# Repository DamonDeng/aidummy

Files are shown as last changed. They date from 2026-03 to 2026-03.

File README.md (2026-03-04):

# Dummy
基于稚晖君原理，木子晓汶PCB二次开发，论坛V2版本模型进行复刻
复刻教学视频链接：
https://www.bilibili.com/video/BV18x421Q7Td/?spm_id_from=333.788&vd_source=a98d716b1df46c01ecbcd3430a76d137

1. 目录描述
- Firmware 包括ref控制板，42，35驱动板所用源代码、ESP32的驱动源码
- Hardware 木子晓汶重新设计的ref控制板，42，35驱动板,的pcb、Gaber、Html所有文件
- Model 目前所有版本复刻dummy机械臂的3D文件
- Software 涵盖 dummy studio 、CTL-Tool、木子开发的simple-cli（待完善）
- Bom 仅为视频链接中V2模型的硬件选型，且对淘宝中出现的链接质量不给予保证
- Docs 包括DH模型参数、谐波减速器参数，PCB外观等

2. 链接
论坛链接 http://dummy.free.mbbs.cc
虚拟机链接：https://pan.baidu.com/s/1SL0wGHDJy_RRZEXTTFYR3g 提取码：1234
网页端串口调试助手 serial.keysking.com
烧录工具下载 https://vcon.io/docs/#quickstart 
Fusion360 https://www.autodesk.com.cn/products/fusion-360/trial-intake
VSCODE 下载地址https://code.visualstudio.com/

3.声明
本视频中讲解的教学内容仅用于，Dummy复刻爱好者学习使用，禁止一切商用行为。

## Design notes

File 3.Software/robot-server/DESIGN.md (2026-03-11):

# Robot Server — Design Documentation

**Project:** Dummy X Robot Arm API Server  
**Location:** `3.Software/robot-server/`  
**Last updated:** 2026-03-11

---

## Overview

The robot server is a FastAPI HTTP/WebSocket server that bridges hardware (robot arm + depth camera) into a clean REST API. It runs locally on the host MacBook at `http://127.0.0.1:3001` and is intended to be called by AI agents, scripts, or any HTTP client.

```
AI Agent / Script
      │
      │  HTTP REST  (port 3001)
      ▼
 robot_server.py   (FastAPI)
      │
      ├── /robot/*     ──► Fibre USB ──► Robot Arm (STM32)
      │
      ├── /camera/*    ──► camera_manager.py
      │                         ├── RGBCamera   ──► imagesnap ──► Astra Pro HD Camera (UVC)
      │                         └── DepthCamera ──► depth_capture (C++) ──► Astra Pro Depth (OpenNI)
      │
      ├── /sequences/* ──► sequences.json (persistent named motion library)
      │
      └── /server/*    ──► mode switch (high_level / low_level)
```

---

## Module Breakdown

### `robot_server.py` — Main FastAPI application

The central server. Handles all HTTP routing and delegates to hardware layers.

**Design principles:**
- All blocking operations run in `asyncio.run_in_executor` to avoid blocking the event loop
- Sim mode (`--sim` flag) replaces hardware with a software mock — same API, same interface
- Stop flag pattern: `POST /robot/stop` sets a flag; all motion commands check it first
- Endpoints are grouped by tag: `Robot`, `Sequences`, `Camera`, `Server`

**Startup sequence:**
1. Parse `--sim` flag
2. If real hardware: connect via Fibre USB, configure joint parameters
3. Start FastAPI app on `127.0.0.1:3001`

---

### `camera_manager.py` — Camera abstraction layer

Provides a clean Python interface to both cameras. Uses subprocess bridging (Phase 1).

**Design decision: subprocess vs ctypes**

We chose subprocess bridging for Phase 1 because:
- The C++ binary (`depth_capture`) was already proven working during experimentation
- Zero risk of crashing the Python server (isolated process)
- Easy to debug (binary can be tested independently)
- Acceptable latency for current use case (~3–4s per capture)

Phase 2 (future): ctypes persistent driver — load `libOrbbecSDK.dylib` directly into Python, keep device open, enable streaming at 7–30fps.

**`RGBCamera`**
- Uses `imagesnap` subprocess (macOS CLI tool)
- Device: `"Astra Pro HD Camera"` (UVC — recognized as standard webcam)
- 2-second warmup for auto-exposure stabilization

**`DepthCamera`**
- Runs `depth_capture` binary via subprocess
- Sets `DYLD_LIBRARY_PATH=orbbec_sdk/` so the binary finds its dylibs
- Parses the **last non-empty stdout line** as JSON — SDK logs appear on earlier lines
- Singleton pattern: `CameraManager.get()`

---

### `depth_capture.cpp` — C++ depth capture tool

Standalone binary that captures one depth frame and saves a colorized PNG.

**Why C++ instead of Python?**
- OrbbecSDK only ships pre-built dylibs for C/C++ API on macOS
- `pyorbbecsdk` has no macOS builds (Linux/Windows only)
- The C++ approach proved working in experimentation; wrapping it is lower risk than reimplementing in Python

**Key implementation details:**
- Requests `OB_FORMAT_Y11` (NOT `OB_FORMAT_Y16`) — the SDK auto-unpacks Y11/Y12 to 16-bit mm values; requesting Y16 causes "No matched profile found" error
- Warms up 11 frames before capturing (first frames are often noisy or under-exposed)
- SDK logs print to stdout during `ob::Context` construction before any log-level call can suppress them — Python wrapper reads only the last stdout line
- Colormap: HSV H=0°(red) → H=240°(blue), auto-scaled to p5–p95 percentile range (avoids outlier clipping)

**Build:**
```bash
make depth_capture
# Requires: clang++, orbbec_sdk/include/, orbbec_sdk/libOrbbecSDK.dylib
```

---

### `orbbec_sdk/` — Orbbec SDK dylibs + headers

Pre-built macOS arm64/x86 universal binaries from OrbbecSDK v1.10.16.

**Why Astra Pro works despite not being "officially supported" on macOS:**
The macOS dylib contains an `OpenNIDeviceInfo.cpp` code path that handles legacy OpenNI protocol devices. The Astra Pro (PID 0x0403) speaks OpenNI protocol and is matched by this path. The official supported device list only covers newer UVC-based devices, but the OpenNI path was compiled in.

**Contents:**
- `libOrbbecSDK.dylib` — main SDK library
- `libob_usb.dylib` — custom USB communication (libusb-based)
- `liblive555.dylib` — network streaming (dependency)
- `include/` — C++ headers for `ob::Context`, `ob::Pipeline`, etc.

---

### `ik_solver.py` — Python IK solver

Analytical closed-form IK solver, ported from the STM32 firmware `DOF6Kinematic::SolveIK`.

**Why Python?**
- Enables pre-computing full paths before streaming to hardware
- 20,000 solves/sec — fast enough for real-time streaming
- Exact match to firmware: same Euler convention (Rz·Ry·Rx), same joint config selection

---

### `sequences.json` — Named motion library

Persistent JSON file storing named sequences (e.g., `elbow-wave`, `home-to-rest`).

**Structure:**
```json
{
  "sequence-name": {
    "name": "sequence-name",
    "description": "...",
    "speed": 20,
    "steps": [
      {"joints": [j1, j2, j3, j4, j5, j6], "duration_ms": 1000},
      ...
    ]
  }
}
```

---

## Camera API Design

### Endpoint design rationale

| Endpoint | Rationale |
|---|---|
| `GET /camera/rgb` | Simplest — just a JPEG image, usable by any client |
| `GET /camera/depth` | Standard 640×480, balance of speed and detail |
| `GET /camera/depth/hires` | 1280×1024 for when precision matters (object detection) |
| `GET /camera/depth/stats` | Stats-only when image not needed (faster, less bandwidth) |
| `GET /camera/snapshot` | Parallel RGB+depth capture for synchronized frames |

**All endpoints are async** — blocking work runs in thread pool via `run_in_executor`.

**Image format choices:**
- RGB → JPEG (smaller, lossy acceptable for visual reference)
- Depth → PNG (lossless required — depth values must be exact)

### Depth colormap

Red→Yellow→Green→Cyan→Blue (HSV 0°→240°):
- **Red** = closest objects (near camera)
- **Blue** = furthest objects (far from camera)
- **Dark gray** = no data (IR dropout on dark/shiny surfaces, or out of range)
- **Auto-scaled** to p5–p95 of valid pixel range — avoids single bright/dark pixel washing out the color range

### Known limitations
1. **~3–4s latency per depth capture** — subprocess startup + 11-frame warmup. Acceptable for single captures; not for streaming.
2. **USB cooldown needed** — rapid successive depth captures can time out; the device needs ~5s between calls.
3. **Dark surface dropout** — robot arm body mostly missing from depth map (black anodized aluminum + black housing). Normal behavior for structured-light cameras.
4. **No depth-to-color alignment** — depth and RGB frames are not spatially aligned (D2C). The depth module and RGB lens are ~5cm apart on the device. Alignment requires OrbbecSDK D2C pipeline (future work).

---

## Robot Arm API Design

### Joint space vs Cartesian space

The arm exposes both:
- **`/robot/move_j`** — direct joint angles (degrees). Fast, predictable, no IK required.
- **`/robot/move_l`** — Cartesian target (x, y, z in mm + a, b, c Euler angles). IK solved server-side in Python (`ik_solver.py`).
- **`/robot/move_l_path`** — pre-computes IK for a full path in Python, streams MoveJ at configurable interval. Enables smooth Cartesian motion.

### Stop flag pattern

`POST /robot/stop` sets a server-side flag. All motion endpoints check this flag and reject commands if set. The flag is cleared by: `/robot/homing`, `/robot/resting`, `/robot/z_home`, `/robot/play_sequence`.

This prevents motion commands from firing after an emergency stop without explicitly resetting to a known safe state.

### Named sequences

Sequences are stored in `sequences.json` and managed via CRUD endpoints. A sequence is a list of joint-angle waypoints with timing. Playing a sequence moves through each waypoint at the configured speed.

---

## Future Roadmap

### Phase 2 Camera: ctypes persistent driver
Replace subprocess with direct `libOrbbecSDK.dylib` loading via Python ctypes:
- Device stays open between API calls → eliminates 3–4s startup latency
- Enables streaming via WebSocket at up to 7fps (1280×1024) or 30fps (640×480)
- New endpoint: `WS /camera/stream`

### Object Detection
`POST /camera/objects/detect`:
1. Capture 1280×1024 depth frame
2. Estimate desk plane (RANSAC or mean of flat region)
3. Find pixels elevated above plane by threshold (e.g. >10mm)
4. Connected component labeling → individual objects
5. Per-object: compute centroid (u, v) → project to 3D (X, Y, Z) using camera intrinsics
6. Return: `[{"id": 0, "x_mm": 245, "y_mm": 180, "z_mm": 142, "w_mm": 45, "h_mm": 30}]`

### Pick-and-Place Loop
```
GET /camera/objects/detect
    → object (X, Y, Z) in camera frame
    → transform to robot arm base frame (requires calibration)
    → POST /robot/move_l  (approach position above object)
    → activate gripper
    → POST /robot/move_l  (lift)
    → POST /robot/move_l  (place position)
    → release gripper
```

### Camera-to-Robot Calibration
Hand-eye calibration: move arm to known positions, observe tip in camera frame, solve for rigid transform between camera frame and robot base frame.

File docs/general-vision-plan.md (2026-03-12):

# General Vision System Plan
*Written: 2026-03-12*

## Goal

Build a general-purpose, environment-agnostic pick-and-place system that:
- Works anywhere (no desk-specific calibration, no environment-specific setup)
- Uses Large Vision Models for object understanding (natural language queries)
- Self-calibrates using the arm itself as the reference target
- Looks like a polished product, not a lab prototype

---

## Architecture Overview

```
User command: "pick up the yellow cup"
        │
        ▼
[Scene Understanding Module]
  RGB frame → VLM (Claude / GPT-4o / Gemini)
  "locate the yellow cup" → pixel bounding box (x, y)
        │
        ▼
[3D Grounding Module]
  pixel (x, y) → depth lookup → 3D point in camera frame
  + camera intrinsics
        │
        ▼
[Coordinate Transform]
  camera frame → robot base frame
  (via stored hand-eye calibration matrix)
        │
        ▼
[Motion Planning]
  3D target position → IK solver → joint angles
  + pre-grasp approach + grasp + lift
        │
        ▼
Robot executes
```

---

## Module 1: Self-Calibration (`arm_calibration.py`)

### Concept
Use the arm tip itself as the calibration target — no markers, no special hardware.
The arm's FK always gives exact 3D tip position. Move to N known positions, detect
the tip in the image via VLM, then solve for camera pose with PnP.

### Process
1. Move arm tip to 8 positions spanning the workspace (FK gives us ground-truth 3D XYZ)
2. At each position: capture RGB photo
3. Ask VLM: *"What are the pixel coordinates (x, y) of the robot arm's tip in this image?"*
4. Collect 8× (3D_point, 2D_pixel) pairs
5. Run cv2.solvePnP() → camera rotation + translation relative to arm base
6. Store as `calibration/camera_to_robot.json`

### Trigger
- API endpoint: `POST /robot/calibrate`
- Re-run only when camera is physically moved

### Key design decisions
- Arm tip can have a **distinctive colored cap** (coral, gold, etc.) — elegant, not a marker
- 8 positions chosen to span the full workspace volume (varying J1, J2, J3)
- VLM provides robustness: works even if arm partially overlaps background
- Fallback: manual pixel annotation if VLM confidence is low

---

## Module 2: Scene Understanding (`scene_understanding.py`)

### Concept
VLM (Claude Vision / GPT-4o) handles all object recognition.
No trained models, no color thresholds, no environment-specific logic.
Generalizes to any object describable in natural language.

### API
```
GET /objects/find?query=yellow+cup
→ {"object": "yellow cup", "pixel_x": 342, "pixel_y": 218, "confidence": 0.92,
   "x_mm": 145.2, "y_mm": -82.3, "z_mm": 48.7}
```

### Process
1. Capture RGB + depth frame
2. Send RGB to VLM: *"Find the {query}. Return its center pixel as JSON: {x, y}"*
3. Look up depth at (x, y) → distance from camera
4. Apply camera intrinsics: pixel → ray → 3D point in camera frame
5. Apply hand-eye transform → 3D in robot frame
6. Return full result

### VLM prompt design
- Structured output request (JSON mode)
- Include image + concise instruction
- Confidence scoring via follow-up: "How confident are you? 0-1"
- Fallback: ask for bounding box if point is uncertain, use center

---

## Module 3: Coordinate Transform

### Camera Intrinsics (Astra Pro)
- Depth camera: known from OrbbecSDK calibration data
- RGB camera: can be estimated via OpenCV calibration checkerboard (one-time)
- Or: use Astra Pro factory intrinsics (640×480: fx≈570, fy≈570, cx=320, cy=240)

### Hand-Eye Transform
- 4×4 homogeneous matrix: `T_robot_camera`
- Solved by `arm_calibration.py` via PnP
- Stored in `calibration/camera_to_robot.json`
- Format: rotation (3×3) + translation (3×1), in mm

### Pixel → 3D
```python
d = depth_frame[y, x]  # mm
X = (x - cx) * d / fx
Y = (y - cy) * d / fy
Z = d
point_camera = [X, Y, Z, 1]
point_robot = T_robot_camera @ point_camera
```

---

## Module 4: Motion Planning (Existing + Extensions)

### Existing
- IK solver (`ik_solver.py`) — fast, analytical, 0.05ms per solve ✓
- `/robot/move_j`, `/robot/move_l_path` — working ✓

### New: Grasp Planning
- Pre-grasp approach: come from above at +100mm Z offset, then descend
- Orientation: J4/J5 to align gripper with object's longest axis (from VLM shape description)
- Contact detection: monitor joint torques or use depth delta

---

## Hardware Design Notes (for Damon to work on)

### Philosophy: Look Designed, Not Experimental

Every modification should look like it was always intended — not added for testing.

### Ideas
1. **Arm tip cap** — small colored sphere/dome, 3D-printable
   - Snap-on design over existing tool tip
   - Distinctive color (coral #FF6B6B, or metallic gold, or electric blue)
   - ~20–25mm diameter — large enough to detect, small enough to look natural
   - This doubles as a calibration reference + visual anchor for VLM

2. **Custom color scheme**
   - All industrial robots have a signature color — KUKA orange, ABB mustard, Fanuc yellow
   - Suggestion: matte black body + accent color at joints (orange rings, or white bands)
   - Or: two-tone matte white + color accents (cleaner, camera-friendly)

3. **Link surface treatment**
   - Forearm link (J3→J5): matte finish helps depth camera (less IR specular)
   - Base + shoulder: could be different color = natural "design accent" + helps VLM distinguish arm segments
   - Avoid pure black on surfaces that face the depth camera (IR dropout)

4. **Logo / identity**
   - A custom nameplate or laser-etched logo on the base
   - Makes it look like a product, not a prototype

---

## Implementation Roadmap

### Phase 1: Prove VLM Tip Detection (Current)
- [x] Concept validated (this document)
- [ ] Move arm to 2 positions, capture photos
- [ ] Test VLM tip pixel detection accuracy
- [ ] Validate: returned (x, y) matches visible tip location

### Phase 2: Full Self-Calibration
- [ ] Build `arm_calibration.py` with 8-pose routine
- [ ] Integrate cv2.solvePnP
- [ ] `POST /robot/calibrate` endpoint
- [ ] Store + load calibration matrix

### Phase 3: Scene Understanding
- [ ] Build `scene_understanding.py`
- [ ] `GET /objects/find?query=...` endpoint
- [ ] Test with various objects and environments

### Phase 4: End-to-End Pick-and-Place
- [ ] Connect all modules
- [ ] Test in original desk setup
- [ ] Test in a new environment (prove generalization)

---

## Files

| File | Location | Status |
|---|---|---|
| This plan | `docs/general-vision-plan.md` | ✓ |
| IK solver | `3.Software/robot-server/ik_solver.py` | ✓ existing |
| Robot server | `3.Software/robot-server/robot_server.py` | ✓ existing |
| Calibration module | `3.Software/robot-server/arm_calibration.py` | planned |
| Scene understanding | `3.Software/robot-server/scene_understanding.py` | planned |
| Calibration data | `3.Software/robot-server/calibration/camera_to_robot.json` | planned |

---

*This system makes the arm general-purpose. The arm + camera become a reusable platform
that can be placed anywhere and told what to do in plain language.*

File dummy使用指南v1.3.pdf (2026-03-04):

Made by zRed

Dummy 组装细节与使用指南

论坛链接 http://dummy.free.mbbs.cc

(木子晓汶版开源链接)https://gitee.com/switchpi/dummy/tree/auk (auk 分支) 虚拟环境下载网盘地址
链接：https://pan.baidu.com/s/1SL0wGHDJy_RRZEXTTFYR3g 提取码：1234 网页端串口调试助手 serial.keysking.com 烧录工具下载 https://vcon.io/docs/#quickstart （我也会上传到论坛）

1 电路连接

Ref to j1 使用同向线，需要交换中间两根 canbus 线 剩下 j1 至 j6 的连接都使用反向线

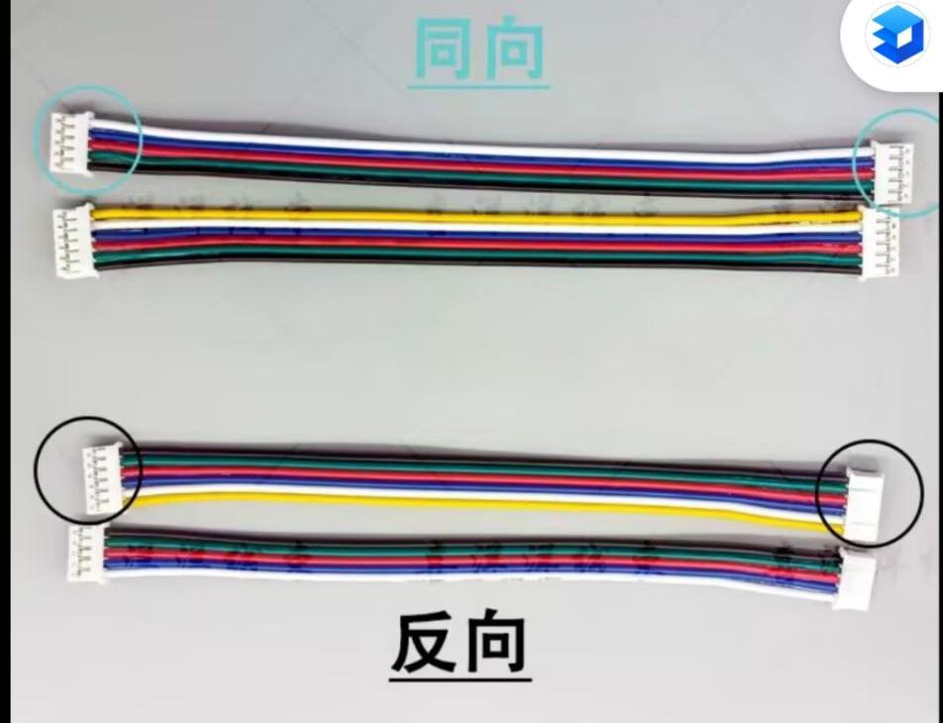
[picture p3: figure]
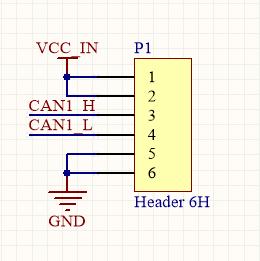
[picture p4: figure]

从原理图可以看出，电源线是两根一组（电机驱动和
ref 板都是这样）

6pin 接口左边 IN 侧 24v 丝印处为 24V,右边 out 侧实际 24v 在左边（靠 IN 侧）
下面有更详细定义

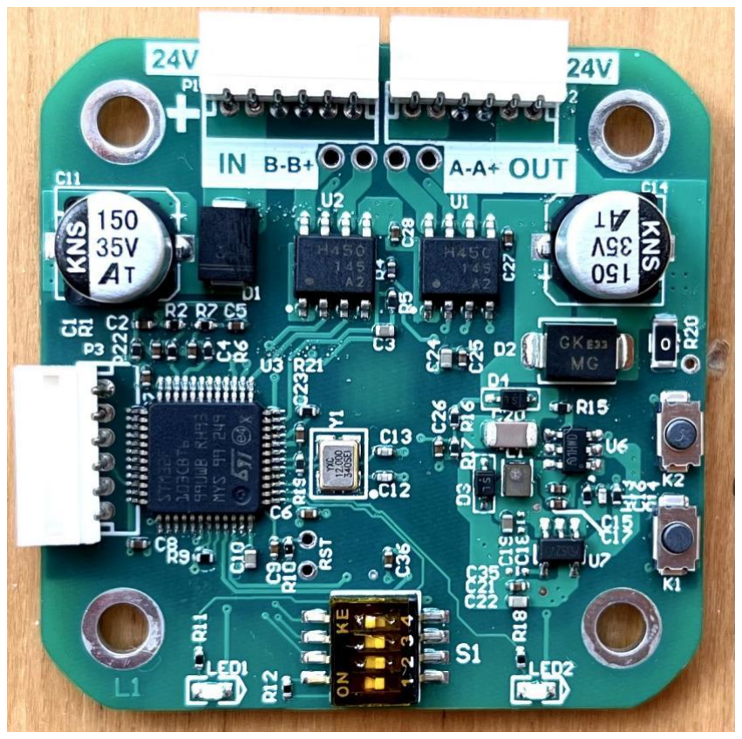
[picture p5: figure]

注意上面两个 6pin 接口的 IN 和 OUT,上一级的 OUT 接上反向线后连到下一级 的 IN 左下第三个 6pin 接口则是程序烧录接口，别接错了

手绘的接线图（偷个懒）
正极线上的那个圆的是自锁开关

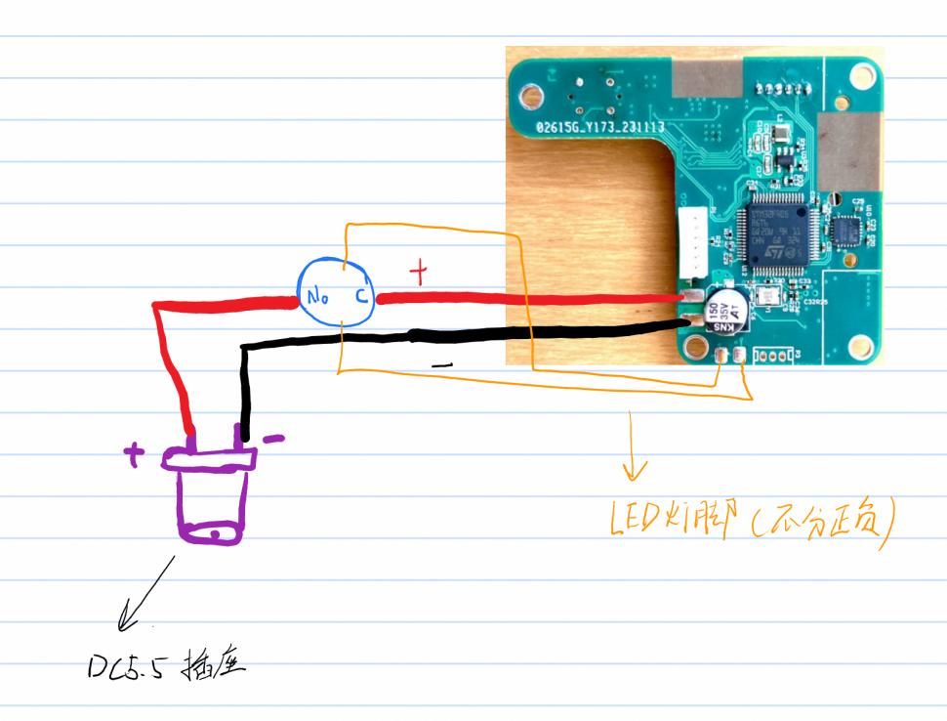
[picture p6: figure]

下面是一些引脚定义，以及拨码方式 注意 j1 到 j6 拨码开关从 1 开始

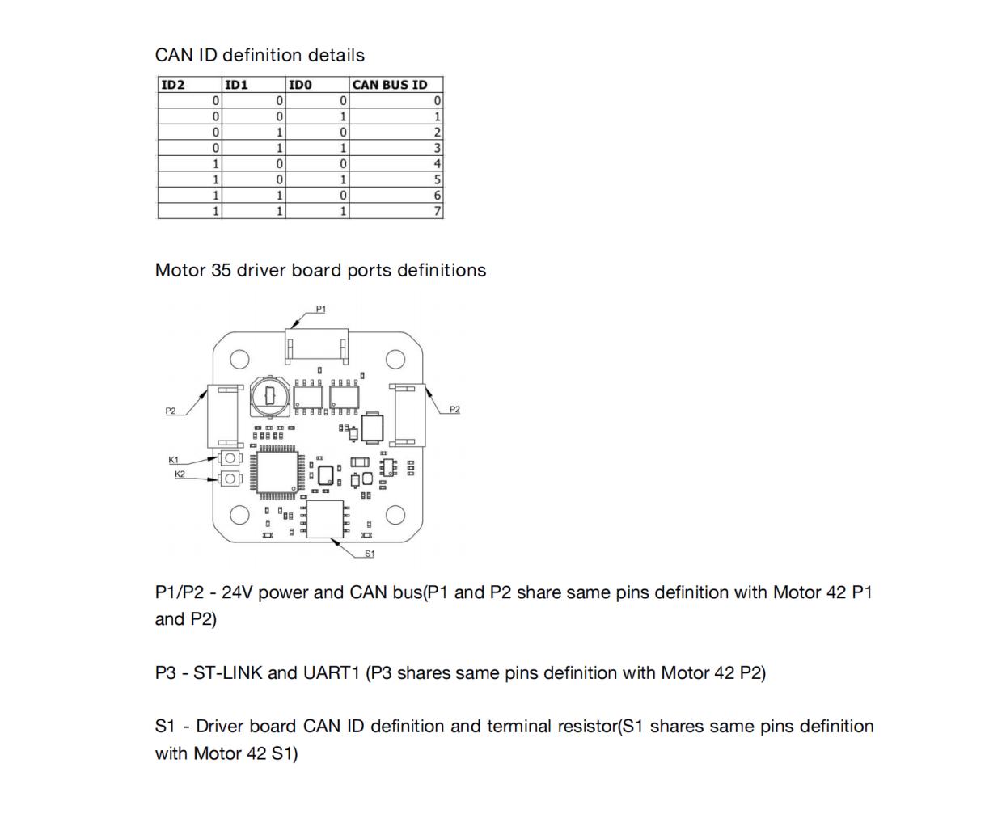
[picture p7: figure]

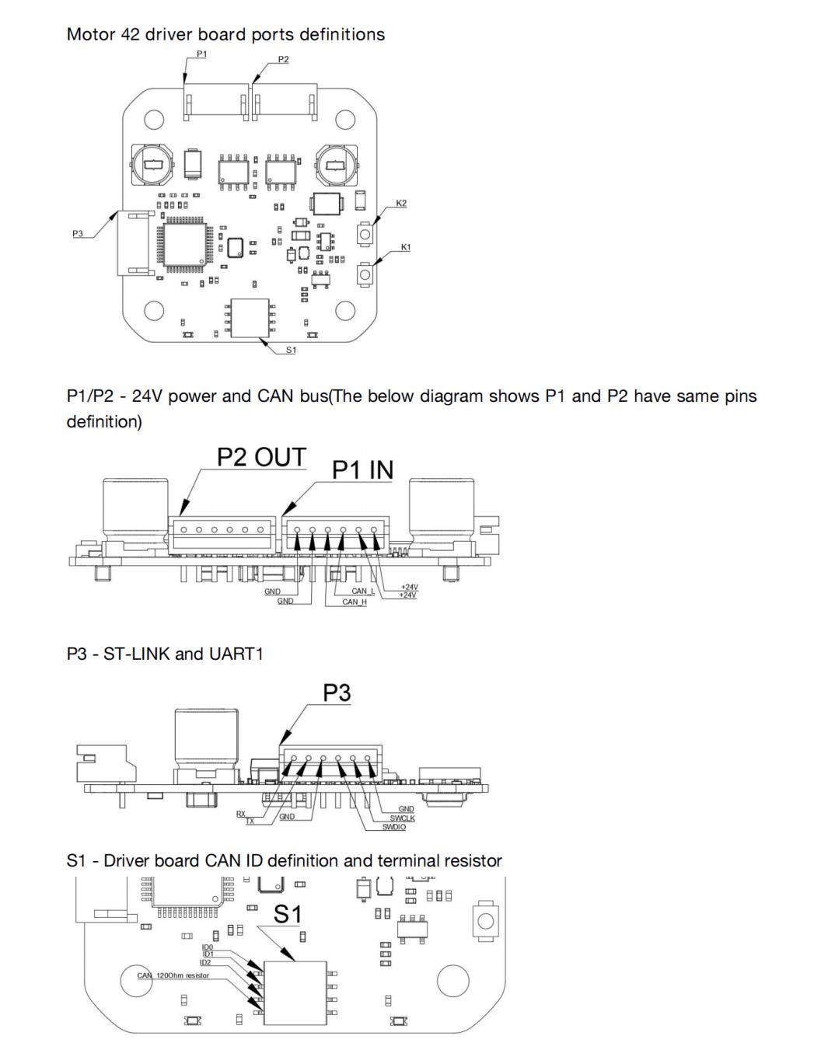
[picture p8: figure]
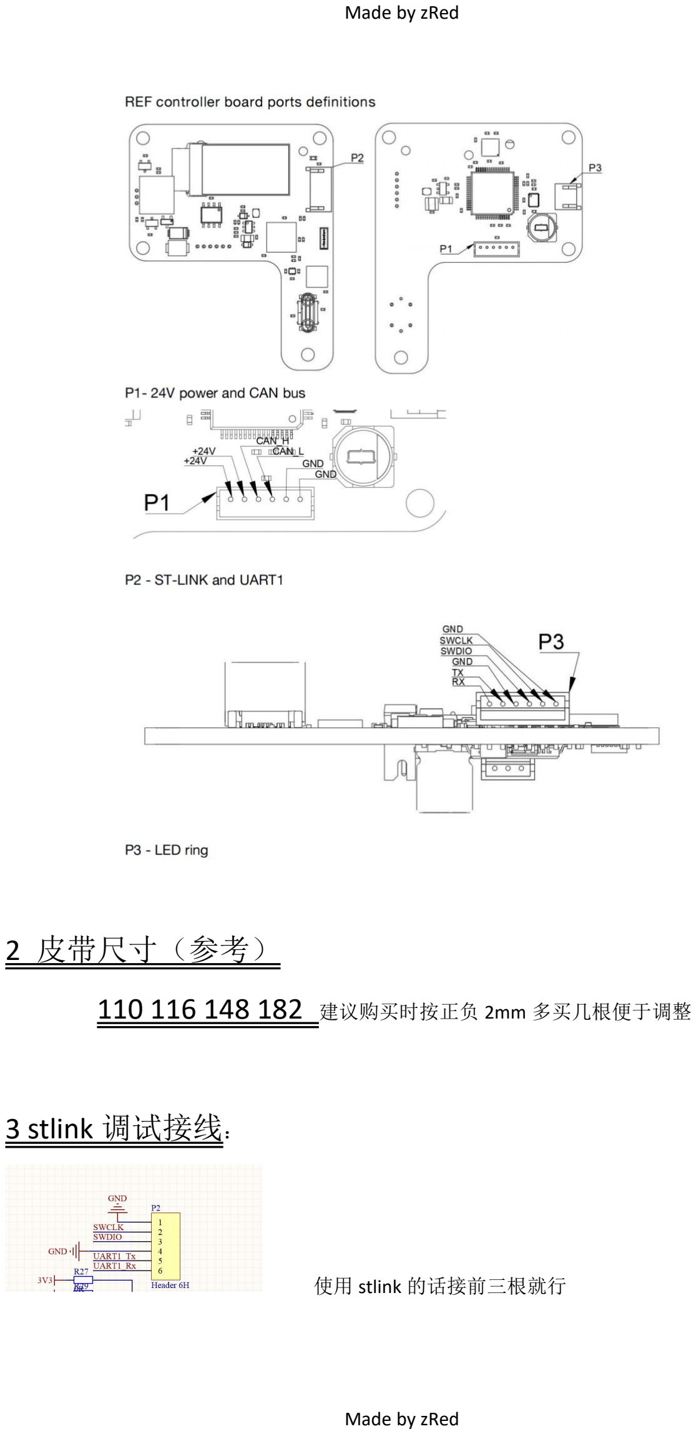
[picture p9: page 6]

2 皮带尺寸（参考）

110 116 148 182 建议购买时按正负 2mm 多买几根便于调整

## 3 stlink 调试接线：

使用 stlink 的话接前三根就行

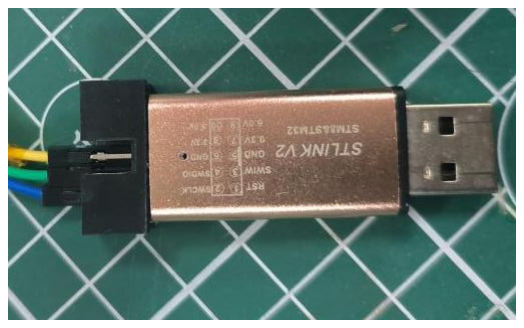
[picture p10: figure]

4 usb 命令使用指南：

本指令清单是用于 usb 命令，即用于 dummy studio，下面的命令以如下格式给出

"命令" | （重点关注）
此命令调用的部分函数 | （有需要的关注这点）
返回值 | （建议关注，以便得知机械臂状态）

机械臂打开后的操作：

### 1 在未上电前将机械臂折叠好，对准刻度

2 上电后在 dummy studio 使用！HOME 命令（发送命令末尾需要选择第四个 | ），机

械臂会展开

### 3 使用！START 命令，机械臂使能，此时可以发送命令，拖动滑条控制机械臂需选择关节轴

手动

接下来给出命令清单

需要加"!"的指令：
例： !START

"STOP" dummy.commandHandler.EmergencyStop();

Respond "Stopped ok"

"START" dummy.SetEnable(true);

Respond "Started ok"

"HOME"

dummy.Homing();
Respond "Started ok"

"CALIBRATION" dummy.CalibrateHomeOffset();

Respond "calibration ok"

"RESET" dummy.Resting();

Respond "Started ok"

"DISABLE" dummy.SetEnable(false);

Respond "Disabled ok

需要加#的指令
例: #GETJPOS

"GETJPOS" Respond(_responseChannel, "ok %.2f %.2f %.2f %.2f %.2f %.2f", dummy.currentJoints.a[0], dummy.currentJoints.a[1], dummy.currentJoints.a[2], dummy.currentJoints.a[3], dummy.currentJoints.a[4], dummy.currentJoints.a[5]); "GETLPOS" dummy.UpdateJointPose6D();

Respond(_responseChannel, "ok %.2f %.2f %.2f %.2f %.2f %.2f", dummy.currentPose6D.X, dummy.currentPose6D.Y, dummy.currentPose6D.Z, dummy.currentPose6D.A, dummy.currentPose6D.B, dummy.currentPose6D.C); "SET_DCE_KP" Respond ok SET MOTOR [%lu] DCE_KP [%lu]", node, kp

Respond "error SET MOTOR [%lu] DCE_KP [%lu] is wrong", node, kp

"SET_DCE_KI" Respond "ok SET MOTOR [%lu] DCE_KI [%lu]", node, kp

Respond "error SET MOTOR [%lu] DCE_KI [%lu] is wrong", node, kp

"SET_DCE_KD" Respond "ok SET MOTOR [%lu] DCE_KD [%lu]", node, kp

Respond "error SET MOTOR [%lu] DCE_KD [%lu] is wrong", node, kp

"REBOOT"

Respond "ok REBOOT MOTOR [%lu]", node
Respond "error REBOOT MOTOR [%lu] is wrong", node

"CMDMODE" dummy.SetCommandMode(mode);

Respond "ok Set command mode to [%lu]", mode

'>' , '@' , '&' uint32_t freeSize = dummy.commandHandler.Push(_cmd);

Respond(_responseChannel, "%d", freeSize);

使用”@”发送末端位姿 例：@175,44,160,-135,-13.54,-14.66 使用”&”发送不同 6 个关节坐标 例 &0,0,134,35,66,0

5 web 端上位机使用指南：

1 首先刷写 esp32 固件，刷写 esp32 时，usb 口反过来插，会识别到 2102 芯片
2 \dummy-auk\dummy-auk\esp32-iot\firmware\examples\esp32\uart-bridge 把 esp32
烧录工具（esputil）复制到这个文件夹下
3 此文件夹下使用命令如下 （/dev/cu.usbserial-0001 需要改成你的串口 号，windows 下一般是 COMX,比如 COM3 COM5）
./esputil -fspi 6,17,8,11,16 -p /dev/cu.usbserial-0001 fl ash bridge.hex
4 等待烧写完毕 打开串口调试助手，重启机械臂
然后会看到串口助手返回以下命令
Unknown | command. | Usage:
set | NAME | VALUE
rm | FILENAME
cat | FILENAME
ls
reboot
wifi | WIFI_NET | WIFI_PASS
CLI | output | end
使用 wifi WIFI_NET WIFI_PASS 这条命令，将 WFIFI_NET 换成你的 wifi 名，WIFI_PASS 换成你的 wifi 密码，这里最好一次输对检查下，输入完成后 结尾加上换行（enter 敲一下）后发送
5 重启一下就能看到返回的 ip 信息，复制 ip 到浏览器就能打开 web 上 位机了

注意事项：

### 1 刷固件要给板子上电 2 USB（typeC）口有正反，上电后电脑识别不到别慌，拔出来，翻一面

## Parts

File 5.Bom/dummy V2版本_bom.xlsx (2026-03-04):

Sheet: REF
Comment | Quantity | Designator | Footprint | Layer | 淘宝价格 | 立创价格 | 备注
0R | 4 | R2, R26, R27, R29 | RES_0402_1 | Top
0.1uF | 9 | C2, C8, C12, C14, C18, C19, C21, C22, C37 | CAP_0402 | Top
1K | 1 | R13 | RES_0402_1 | Top
1M | 1 | R16 | RES_0402_1 | Top
1uF | 1 | C3 | CAP_0402 | Top
1.8K | 1 | R14 | RES_0402_1 | Top
2K | 2 | R12, R18 | RES_0402_1 | Top
4.7K | 3 | R19, R20, R23 | RES_0402_1 | Top
4.7uF | 1 | C16 | C0603 | Top
5.1K | 2 | R8, R9 | RES_0402_1 | Top
6.8uH | 1 | L1 | IND-201612 | Top
10K | 6 | R1, R5, R10, R11, R15, R21 | RES_0402_1 | Top
10uF | 4 | C1, C15, C26, C27 | CAP_0402 | Top
12K | 2 | R4, R6 | RES_0402_1 | Top
100pF | 1 | C11 | CAP_0402 | Top
200R | 1 | R3 | RES_0402_1 | Top
560K | 1 | R22 | RES_0402_1 | Top
AO3400A | 1 | Q2 | SOT23-3 | Top
AO3401A | 1 | Q3 | SOT23-3 | Top
BC847BVC-7 | 1 | Q1 | SOT563-6 | Top
CP2102 | 1 | U1 | QFN-28 | Top | 7.5 | 12.8
ESP32_SIP | 1 | U2 | QFN-48_7X7 | Top | 7.8 | 23
Header 6H | 1 | P2 | CONN-TH_HC-ZH1.5-6A-s | Top
LED GREEN | 1 | LED1 | LED-0603 | Top
ME3116 | 1 | U8 | SOT23-6 | Top
MLT-7525 | 1 | U4 | BUZ-SMD_4P-L7.5-W7.5-P7.59-TL | Top
NRF24L01 | 1 | U7 | NRF24L01-MODULE | Top | 5.8
OLED-12880 | 1 | 1 | OLED-12880 | Top
RAINSUN | 1 | A1 | ANT-Rainsun-AN5120 | Top | 1
S8050 | 1 | VT1 | SMT_TRIODE_NPN | Top
SMBJ28CA | 1 | D3 | SMBJ-CA_MFG | Top
SN65HVD232D | 1 | U11 | SO-8 | Top | 3 | 6
SS54 | 1 | D2 | DO-214AC | Top
USB-TYPE-C-STAND | 1 | J1 | USB-TYPE-C-STAND | Top
b5819W | 2 | D4, D5 | SOD-323 | Top
0R | 2 | R25, R31 | RES_0402_1 | Bottom
0.1uF | 10 | C4, C20, C23, C25, C28, C29, C30, C31, C32, C36 | CAP_0402 | Bottom
1M | 1 | R30 | RES_0402 | Bottom
2K | 2 | R7, R17 | RES_0402_1 | Bottom
2.2nF | 1 | C24 | CAP_0402 | Bottom
2.2uH | 1 | L2 | IND-252012A-2R2 | Bottom
10K | 2 | R28, R34 | RES_0402_1 | Bottom
10uF | 3 | C33, C34, C35 | CAP_0402 | Bottom
20pF | 2 | C7, C9 | CAP_0402 | Bottom
20pF | 1 | C13 | CAP_0402 | Bottom
22uF | 3 | C5, C10, C17 | C0603 | Bottom
22.1K | 1 | R35 | RES_0402_1 | Bottom
100K | 1 | R33 | RES_0402_1 | Bottom
120R/NC | 1 | R24 | RES_0402_1 | Bottom
220uF/25V | 1 | C6 | CAP-SMD_BD8.0-L8.3-W8.3-LS9.3-FD | Bottom
Header 3 | 1 | P3 | CONN-TH_HC-ZH1.5-3A-S | Bottom
Header 6H | 1 | P1 | CONN-TH_HC-ZH1.5-6A | Bottom
MPU6050 | 1 | U10 | QFN-24 | Bottom | 4.7
STM32F405RGT6 | 1 | U12 | LQFP-64_N | Bottom | 19.8 | 29.6
SY8089 2A | 1 | U3 | SOT23-5 | Bottom
XTAL-4 | 1 | Y1 | LC-SMD-3225_4P | Bottom
红色为淘宝购买合计：162元 |  |  |  | 元器件合计285元 电路板制作费用110元
绿色为商城购买合计： 123元
淘宝链接如下，不保证好坏哈，我测试过大部分没有问题
NRF24L01+无线收发模块 2.4G数传发射接收通信模块迷你功率加强版-tmall.com天猫 (https://detail.tmall.com/item.htm?id=610450154250&spm=a1z0d.6639537/tb.1997196601.4.561a7484jP7wVk)
原装正品 MPU6050 芯片 陀螺仪/加速度计 6轴 可编程 I2C QFN-24-tmall.com天猫 (https://detail.tmall.com/item.htm?id=737728054889&skuId=5092115920192)
原装MT6816CT-ACD 6816 SOP-8 零延迟磁角线性位置传感器现货直发-淘宝网 (taobao.com) (https://item.taobao.com/item.htm?spm=a1z0d.6639537/tb.1997196601.22.561a7484jP7wVk&id=737167465604)
LP2992AIM5X/2981AIM5-3.3/NOPB低压差线性稳压LDO贴片SOT23-5-淘宝网 (taobao.com) (https://item.taobao.com/item.htm?id=600231832095&spm=a1z0d.6639537/tb.1997196601.32.561a7484jP7wVk)
全新原装 TB67H450FNG TB67H451FNGTB67H450 67H451 贴片SOP8-淘宝网 (taobao.com) (https://item.taobao.com/item.htm?spm=a1z0d.6639537/tb.1997196601.270.561a7484jP7wVk&id=679845275070)
原装正品 贴片 CP2102-GMR QFN-28 USB转UART 桥接控制器芯片-淘宝网 (taobao.com) (https://item.taobao.com/item.htm?spm=a1z0d.6639537/tb.1997196601.52.561a7484jP7wVk&id=522575454240)
原装正品 ESP32-D0WD-V3 QFN-48 双核Wi-Fi&蓝牙MCU无线收发芯片-淘宝网 (taobao.com) (https://item.taobao.com/item.htm?spm=a1z0d.6639537/tb.1997196601.294.561a7484jP7wVk&id=634773385996)
原装正品 AN2051-245 2.4G全向天线 RF射频蓝牙 陶瓷贴片WIFI内置-淘宝网 (taobao.com) (https://item.taobao.com/item.htm?spm=a1z0d.6639537/tb.1997196601.334.561a7484jP7wVk&id=558699169012)
SN65HVD232DR 232D VP233 234 235 251 252 255 256 收发器 SOP-8-tmall.com天猫 (https://detail.tmall.com/item.htm?id=724937054666&spm=a1z0d.6639537/tb.1997196601.72.561a7484jP7wVk)
STM32F103C8T6/CBT6/RBT6/VBT6/RET6/RDT6/ZET6/VET6/VCT6/RCT6原-淘宝网 (taobao.com) (https://item.taobao.com/item.htm?spm=a1z0d.6639537/tb.1997196601.79.561a7484jP7wVk&id=743299994595)
STM32F405RGT6 LQFP-64 全新原装正品 优势低价 渠道直售现货-淘宝网 (taobao.com) (https://item.taobao.com/item.htm?id=743062203353&spm=a1z0d.6639537/tb.1997196601.387.561a7484jP7wVk)
屏幕优信0.78寸OLED裸屏显示液晶屏 分 辨率128*80 SPI接口 SH1107驱动https://item.taobao.com/item.htm?_u=d23g2a9g7f8b&id=665034068875&spm=a1z09.2.0.0.567c2e8dsQorFS

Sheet: Motor-42
Comment | Description | Designator | Footprint | Quantity | Layer | 淘宝价格 | LC价格 | 备注
0.1R | Resistor | R3, R8 | 1206-RES | 2 | Bottom
10uF/50V | Capacitor, chip, ceramic | C29, C30, C31, C32, C33, C34 | 1206-CAP | 6 | Bottom
MT6816 | Magnetic Position Sensor | U8 | SO-8 | 1 | Bottom | 9 | 18.39
SN65HVD232D |  | U5 | so-8 | 1 | Bottom | 3 | 6
0 | Resistor | R21, R22 | RES_0402 | 2 | Top
0R | Resistor | R20 | 1206-RES | 1 | Top
0.1uF | Capacitor | C1, C2, C4, C5, C6, C7, C8, C9, C15, C17, C18, C21, C23, C25, C26, C27, C28, C35, C36 | CAP_0402 | 19 | Top
1K | Resistor | R1, R2, R6, R7, R11, R17, R18 | RES_0402 | 7 | Top
1M | Resistor | R15, R19 | RES_0402 | 2 | Top
1.8K | Resistor | R14 | RES_0402 | 1 | Top
3.3K | Resistor | R5 | RES_0402 | 1 | Top
6.8uH |  | L1 | IND-201612 | 1 | Top
10K | Resistor | R9, R10, R13, R16 | RES_0402 | 4 | Top
10uF | Capacitor | C3, C10, C19, C22, C24 | CAP_0402 | 5 | Top
10uF/50V | Capacitor | C20 | 1206-CAP | 1 | Top
20pF | Capacitor | C12, C13 | CAP_0402 | 2 | Top
100pF | Capacitor | C16 | CAP_0402 | 1 | Top
120R | Resistor | R12 | RES_0402 | 1 | Top
220uF/25V | Capacitor, chip, ceramic | C11, C14 | CAP-SMD_BD8.0-L8.3-W8.3-LS9.3-FD | 2 | Top
DSHP04TSGER | DIP Switches / SIP Switches 4 pos. low profile Btm Seal Tape J Bend | S1 | SW-SMD_DSHP04TS-S | 1 | Top
Header 6H | Header, 6-Pin, Right Angle | P1, P2, P3 | CONN-TH_HC-ZH1.5-6A-s | 3 | Top
LED GREEN | LED GRN SGL RA 25mA 4.1V SMD | LED1, LED2 | LED-0603 | 2 | Top
LP2992 3V3 | LDO | U7 | SOT23-5 | 1 | Top
ME3116 | DC-DC | U6 | SOT23-6 | 1 | Top
NCP15XH103F03RC | THERMISTOR 10K OHM NTC 0402 SMD | R4 | RES_0402 | 1 | Top
SMBJ28CA |  | D2 | SMBJ-CA_MFG | 1 | Top
SS54 | Diode | D1 | DO-214AC | 1 | Top
STM32F103CBT6 | ARM Cortex-M3 32-bit MCU, 128 KB Flash, 20 KB Internal RAM, 37 I/Os, 48-pin LQFP, -40 to 85 degC, Tray | U3 | LQFP-48 | 1 | Top | 16.8 | 29
TACT 2P | Button | K1, K2 | ButtonTACT_3x4x2_180 | 2 | Top |  |  | TS1185
TB67H450FNG | PWM Chopper Type DC Brushed Motor Driver | U1, U2 | SO-8-PAD | 2 | Top | 1.48 | 3.25
XTAL-4 | Crystal | Y1 | LC-SMD-3225_4P | 1 | Top
二极管-5819W | 40V | D3, D4 | SOD-323 | 2 | Top

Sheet: Motor-35
Comment | Quantity | Description | Designator | Footprint | Layer | 淘宝价格 | LC价格 | 备注
0R | 1 | Resistor | R20 | 1206-RES | Bottom
0.1R | 2 | Resistor | R3, R8 | 1206-RES | Bottom
0.1uF | 2 | Capacitor | C21, C25 | CAP_0402 | Bottom
10uF | 2 | Capacitor | C22, C24 | CAP_0402 | Bottom
10uF/50V | 4 | Capacitor, chip, ceramic | C29, C30, C31, C32 | 1206-CAP | Bottom
LP2992 3V3 | 1 | LDO | U7 | SOT23-5 | Bottom
MT6816 | 1 | Magnetic Position Sensor | U8 | SO-8 | Bottom
SN65HVD232D | 1 |  | U5 | so-8 | Bottom
SS54 | 1 | Diode | D1 | DO-214AC | Bottom
0 | 2 | Resistor | R21, R22 | RES_0402 | Top
0.1uF | 15 | Capacitor | C1, C2, C4, C5, C6, C7, C8, C9, C15, C17, C18, C23, C27, C28, C36 | CAP_0402 | Top
1K | 6 | Resistor | R1, R2, R6, R7, R11, R18 | RES_0402 | Top
1M | 2 | Resistor | R15, R19 | RES_0402 | Top
1.8K | 1 | Resistor | R14 | RES_0402 | Top
3.3K | 1 | Resistor | R5 | RES_0402 | Top
6.8uH | 1 |  | L1 | IND-201612 | Top
10K | 3 | Resistor | R9, R10, R13 | RES_0402 | Top
10uF | 3 | Capacitor | C3, C10, C19 | CAP_0402 | Top
10uF/50V | 1 | Capacitor | C20 | 1206-CAP | Top
20pF | 2 | Capacitor | C12, C13 | CAP_0402 | Top
100pF | 1 | Capacitor | C16 | CAP_0402 | Top
120R | 1 | Resistor | R12 | RES_0402 | Top
220uF/25V | 1 | Capacitor, chip, ceramic | C11 | CAP-SMD_BD8.0-L8.3-W8.3-LS9.3-FD | Top
DSHP04TSGER | 1 | DIP Switches / SIP Switches 4 pos. low profile Btm Seal Tape J Bend | S1 | SW-SMD_DSHP04TS-S | Top
Header 6H | 3 | Header, 6-Pin, Right Angle | P1, P2, P3 | CONN-TH_HC-ZH1.5-6A-s | Top
LED GREEN | 2 | LED GRN SGL RA 25mA 4.1V SMD | LED1, LED2 | LED-0603 | Top
ME3116 | 1 | DC-DC | U6 | SOT23-6 | Top
NCP15XH103F03RC | 1 | THERMISTOR 10K OHM NTC 0402 SMD | R4 | RES_0402 | Top
SMBJ28CA | 1 |  | D2 | SMBJ-CA_MFG | Top
STM32F103CBT6 | 1 | ARM Cortex-M3 32-bit MCU, 128 KB Flash, 20 KB Internal RAM, 37 I/Os, 48-pin LQFP, -40 to 85 degC, Tray | U3 | LQFP-48 | Top | 4.48 | 10.56
TACT 2P | 2 | Button | K1, K2 | ButtonTACT_3x4x2_180 | Top |  |  | TS1185
TB67H450FNG | 2 | PWM Chopper Type DC Brushed Motor Driver | U1, U2 | SO-8-PAD | Top | 1.48 | 3.25
XTAL-4 | 1 | Crystal | Y1 | LC-SMD-3225_4P | Top
二极管-5819W | 2 | 40V | D3, D4 | SOD-323 | Top

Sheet: 部分淘宝购买版123元
购买类型 | 商品编号 | 物料编码 | 商品分类 | 名称 | 商品型号 | 品牌 | 封装规格 | 单个毛重 | 购买数量 | 商品单价 | 金额
常规 | C95299 |  | 蜂鸣器 | MLT-7525 编带 | MLT-7525 | 华能 | SMD,7.5x7.5mm | 0.000565000 | 5 | ￥1.3960 | ￥6.98
常规 | C19666 |  | 贴片电容(MLCC) | 4.7uF ±10% 16V 编带 | CL10A475KO8NNNC | SAMSUNG(三星) | 0603 | 0.000040000 | 50 | ￥0.060929 | ￥3.05
常规 | C170075 |  | 贴片电容(MLCC) | 10uF ±20% 50V 编带 | 1206X106M500NT | FH(风华) | 1206 | 0.000048000 | 20 | ￥0.285189 | ￥5.70
常规 | C2682774 |  | 无源晶振 | 8MHz ±10ppm 20pF YSX321SL 编带 | X32258MSB4SI | YXC(扬兴晶振) | SMD3225-4P | 0.000050000 | 5 | ￥0.9797 | ￥4.90
常规 | C4109 |  | 贴片电阻 | 2kΩ ±1% 62.5mW 厚膜电阻 编带 | 0402WGF2001TCE | UNI-ROYAL(厚声) | 0402 | 0.000009000 | 100 | ￥0.003045 | ￥0.30
常规 | C1531 |  | 贴片电容(MLCC) | 2.2nF ±10% 50V 编带 | 0402B222K500NT | FH(风华) | 0402 | 0.000022000 | 100 | ￥0.005762 | ￥0.58
常规 | C77131 |  | NTC热敏电阻 | 10kΩ 电阻精度:±1% 3380K 编带 | NCP15XH103F03RC | muRata(村田) | 0402 | 0.000015000 | 50 | ￥0.077806 | ￥3.89
常规 | C163478 |  | 贴片电阻 | 厚膜电阻 22.1kΩ ±1% 62.5mW 编带 | RC0402FR-0722K1L | YAGEO(国巨) | 0402 | 0.000009000 | 100 | ￥0.003984 | ￥0.40
常规 | C7471880 |  | 贴片型铝电解电容 | 150uF ±20% 35V 编带 | 189RV0018 | KNSCHA(科尼盛) | SMD,D6.3xL7.7mm | 0.000638400 | 10 | ￥0.268320 | ￥2.68
常规 | C97643 |  | DC-DC电源芯片 | ME3116AM6G 编带 | ME3116AM6G | MICRONE(南京微盟) | SOT-23-6 | 0.000055000 | 10 | ￥0.8689 | ￥8.69
常规 | C26083 |  | 贴片电阻 | 1MΩ ±1% 62.5mW 厚膜电阻 编带 | 0402WGF1004TCE | UNI-ROYAL(厚声) | 0402 | 0.000009000 | 100 | ￥0.003249 | ￥0.32
常规 | C726872 |  | 静电和浪涌保护(TVS/ESD) | SMBJ28CA 编带 | SMBJ28CA | TWGMC(台湾迪嘉) | SMB | 0.000152000 | 10 | ￥0.211792 | ￥2.12
常规 | C11702 |  | 贴片电阻 | 1kΩ ±1% 62.5mW 厚膜电阻 编带 | 0402WGF1001TCE | UNI-ROYAL(厚声) | 0402 | 0.000009000 | 100 | ￥0.003136 | ￥0.31
常规 | C561517 |  | 轻触开关 | 4*3*2mm 立贴 轻触开关 编带 | TS-1185-B-A-B-A | XKB Connectivity(中国星坤) | SMD | 0.000140000 | 20 | ￥0.357936 | ￥7.16
常规 | C7371905 |  | 发光二极管/LED | XL-1608PGC-06 编带 | XL-1608PGC-06 | XINGLIGHT(成兴光) | 0603 | 0.000020170 | 50 | ￥0.054250 | ￥2.71
常规 | C25752 |  | 贴片电阻 | 12kΩ ±1% 62.5mW 厚膜电阻 编带 | 0402WGF1202TCE | UNI-ROYAL(厚声) | 0402 | 0.000009000 | 100 | ￥0.003137 | ￥0.31
常规 | C25871 |  | 贴片电阻 | 1.8kΩ ±1% 62.5mW 厚膜电阻 编带 | 0402WGF1801TCE | UNI-ROYAL(厚声) | 0402 | 0.000009000 | 100 | ￥0.003299 | ￥0.33
常规 | C60491 |  | 贴片电阻 | 厚膜电阻 100kΩ ±1% 62.5mW 编带 | RC0402FR-07100KL | YAGEO(国巨) | 0402 | 0.000009000 | 100 | ￥0.003330 | ￥0.33
常规 | C60490 |  | 贴片电阻 | 厚膜电阻 10kΩ ±1% 62.5mW 编带 | RC0402FR-0710KL | YAGEO(国巨) | 0402 | 0.000009000 | 100 | ￥0.003197 | ￥0.32
常规 | C9002 |  | 无源晶振 | 12MHz ±10ppm 20pF YSX321SL 编带 | X322512MSB4SI | YXC(扬兴晶振) | SMD3225-4P | 0.000047000 | 10 | ￥0.372347 | ￥3.72
常规 | C17168 |  | 贴片电阻 | 0Ω ±1% 62.5mW 厚膜电阻 编带 | 0402WGF0000TCE | UNI-ROYAL(厚声) | 0402 | 0.000009000 | 100 | ￥0.003049 | ￥0.30
常规 | C15525 |  | 贴片电容(MLCC) | 10uF ±20% 6.3V 编带 | CL05A106MQ5NUNC | SAMSUNG(三星) | 0402 | 0.000016500 | 100 | ￥0.030332 | ￥3.03
常规 | C1554 |  | 贴片电容(MLCC) | 20pF ±5% 50V 编带 | 0402CG200J500NT | FH(风华) | 0402 | 0.000022000 | 100 | ￥0.006676 | ￥0.67
常规 | C7420331 |  | 肖特基二极管 | 电压:40V 电流:1A 编带 | B5819WS | 宏迦橙 | SOD-323 | 0.000029000 | 50 | ￥0.073235 | ￥3.66
常规 | C25905 |  | 贴片电阻 | 5.1kΩ ±1% 62.5mW 厚膜电阻 编带 | 0402WGF5101TCE | UNI-ROYAL(厚声) | 0402 | 0.000009000 | 100 | ￥0.003127 | ￥0.31
常规 | C25087 |  | 贴片电阻 | 200Ω ±1% 62.5mW 厚膜电阻 编带 | 0402WGF2000TCE | UNI-ROYAL(厚声) | 0402 | 0.000009000 | 100 | ￥0.003063 | ￥0.31
常规 | C22452 |  | 肖特基二极管 | 电压:40V 电流:5A 编带 | SS54 | MDD | SMA(DO-214AC) | 0.000094000 | 10 | ￥0.240837 | ￥2.41
常规 | C25900 |  | 贴片电阻 | 4.7kΩ ±1% 62.5mW 厚膜电阻 编带 | 0402WGF4701TCE | UNI-ROYAL(厚声) | 0402 | 0.000009000 | 100 | ￥0.003081 | ￥0.31
常规 | C7429528 |  | 线对板/线对线连接器 | 1x6P 间距:1.5mm 直插 系列:ZH 袋装 | ZX-ZH1.5-ZZ6P | Megastar(兆星) | 插件,P=1.5mm | 0.000194400 | 10 | ￥0.201855 | ￥2.02
常规 | C501945 |  | 功率电感 | 6.8uH ±20% 870mA 编带 | VLS201612HBX-6R8M-1 | TDK | 0806 | 0.000011000 | 20 | ￥0.350391 | ￥7.01
常规 | C306862 |  | 场效应管(MOSFET) | P沟道 耐压:30V 电流:4.2A 编带 | AO3401A | BORN(伯恩半导体) | SOT-23 | 0.000032000 | 10 | ￥0.249179 | ￥2.49
常规 | C3293144 |  | 拨码开关 | 4位 1.27mm间距贴片型 KE拨码开关 编带 | DSHP04TSGER | 康深 | SMD-8P,5.4x6.6mm | 0.000350000 | 6 | ￥2.77 | ￥16.62
常规 | C14445 |  | 贴片电容(MLCC) | 1uF ±10% 10V 编带 | CL05A105KP5NNNC | SAMSUNG(三星) | 0402 | 0.000016500 | 100 | ￥0.011230 | ￥1.12
常规 | C347475 |  | 场效应管(MOSFET) | N沟道 耐压:30V 电流:5.8A 编带 | AO3400A | UMW(友台半导体) | SOT-23 | 0.000033000 | 20 | ￥0.172511 | ￥3.45
常规 | C7429534 |  | 线对板/线对线连接器 | 1x3P 间距:1.5mm 弯插 系列:ZH 袋装 | ZX-ZH1.5-WZ3P | Megastar(兆星) | 弯插,P=1.5mm | 0.000126900 | 20 | ￥0.111244 | ￥2.22
常规 | C325569 |  | 贴片电阻 | 560kΩ 1% 62.5mW 编带 | RMC0402560K1%N | Tyohm(幸亚电阻) | 0402 | 0.000009000 | 100 | ￥0.013263 | ￥1.33
常规 | C78988 |  | DC-DC电源芯片 | SY8089AAAC 编带 | SY8089AAAC | silergy(矽力杰) | SOT-23-5 | 0.000046000 | 5 | ￥1.2206 | ￥6.10
常规 | C25334 |  | 贴片电阻 | 100mΩ ±1% 250mW 厚膜电阻 编带 | 1206W4F100LT5E | UNI-ROYAL(厚声) | 1206 | 0.000030000 | 100 | ￥0.029143 | ￥2.91
常规 | C1546 |  | 贴片电容(MLCC) | 100pF ±5% 50V 编带 | 0402CG101J500NT | FH(风华) | 0402 | 0.000022000 | 100 | ￥0.005566 | ￥0.56
常规 | C59461 |  | 贴片电容(MLCC) | 22uF ±20% 6.3V 编带 | CL10A226MQ8NRNC | SAMSUNG(三星) | 0603 | 0.000045000 | 50 | ￥0.052209 | ￥2.61
常规 | C2146 |  | 三极管(BJT) | NPN 电流:500mA 耐压:25V H档(200-350) 编带 | S8050 J3Y | CJ(江苏长电/长晶) | SOT-23 | 0.000036000 | 50 | ￥0.089660 | ￥4.48
常规 | C720628 |  | USB连接器 | Type-C 母 立贴 编带 | TYPEC-303-ACP16 | XUNPU(讯普) | SMD | 0.000990000 | 1 | ￥3.11 | ￥3.11
常规 | C60474 |  | 贴片电容(MLCC) | 100nF ±10% 16V 编带 | CC0402KRX7R7BB104 | YAGEO(国巨) | 0402 | 0.000012020 | 100 | ￥0.004896 | ￥0.49
常规 | C25079 |  | 贴片电阻 | 120Ω ±1% 62.5mW 厚膜电阻 编带 | 0402WGF1200TCE | UNI-ROYAL(厚声) | 0402 | 0.000009000 | 100 | ￥0.003163 | ￥0.32
常规 | C25890 |  | 贴片电阻 | 3.3kΩ ±1% 62.5mW 厚膜电阻 编带 | 0402WGF3301TCE | UNI-ROYAL(厚声) | 0402 | 0.000009000 | 100 | ￥0.002998 | ￥0.30
常规 | C150761 |  | 三极管(BJT) | 耐压:45V 电流:100mA 2个NPN 编带 | BC847BVC-7 | DIODES(美台) | SOT-563 | 0.000027000 | 5 | ￥0.410115 | ￥2.05
常规 | C280577 |  | 功率电感 | 2.2uH ±20% 3.3A 编带 | MHCD252012A-2R2M-A8S | chilisin(奇力新) | SMD | 0.000063000 | 10 | ￥0.228092 | ￥2.28
常规 | C7429537 |  | 线对板/线对线连接器 | 1x6P 间距:1.5mm 弯插 系列:ZH 袋装 | ZX-ZH1.5-WZ6P | Megastar(兆星) | 弯插,P=1.5mm | 0.000215000 | 10 | ￥0.214088 | ￥2.14
常规 | C17888 |  | 贴片电阻 | 0Ω ±1% 250mW 厚膜电阻 编带 | 1206W4F0000T5E | UNI-ROYAL(厚声) | 1206 | 0.000030000 | 100 | ￥0.019218 | ￥1.92
订货 | C194087 |  | 贴片型铝电解电容 | 220uF ±20% 25V 管装 | UUN1E221MNQ1ZD | Nichicon(尼吉康) | SMD | 0.002700000 | 2 | ￥2.49 | ￥4.98

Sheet: 一键购买版443元
购买类型 | 商品编号 | 物料编码 | 商品分类 | 名称 | 商品型号 | 品牌 | 封装规格 | 单个毛重 | 购买数量 | 商品单价 | 金额
常规 | C95299 |  | 蜂鸣器 | MLT-7525 编带 | MLT-7525 | 华能 | SMD,7.5x7.5mm | 0.000565000 | 5 | ￥1.3960 | ￥6.98
常规 | C19666 |  | 贴片电容(MLCC) | 4.7uF ±10% 16V 编带 | CL10A475KO8NNNC | SAMSUNG(三星) | 0603 | 0.000040000 | 50 | ￥0.060929 | ￥3.05
常规 | C170075 |  | 贴片电容(MLCC) | 10uF ±20% 50V 编带 | 1206X106M500NT | FH(风华) | 1206 | 0.000048000 | 20 | ￥0.285189 | ￥5.70
常规 | C2682774 |  | 无源晶振 | 8MHz ±10ppm 20pF YSX321SL 编带 | X32258MSB4SI | YXC(扬兴晶振) | SMD3225-4P | 0.000050000 | 5 | ￥0.9797 | ￥4.90
常规 | C4109 |  | 贴片电阻 | 2kΩ ±1% 62.5mW 厚膜电阻 编带 | 0402WGF2001TCE | UNI-ROYAL(厚声) | 0402 | 0.000009000 | 100 | ￥0.003045 | ￥0.30
常规 | C15742 |  | 单片机(MCU/MPU/SOC) | STM32F405RGT6 托盘 | STM32F405RGT6 | ST(意法半导体) | LQFP-64(10x10) | 0.001400000 | 1 | ￥29.60 | ￥29.60
常规 | C30530 |  | CAN芯片 | 1Mbps 3V~3.6V 编带 | SN65HVD232DR | TI(德州仪器) | SOIC-8 | 0.000173000 | 7 | ￥6.07 | ￥42.49
常规 | C1531 |  | 贴片电容(MLCC) | 2.2nF ±10% 50V 编带 | 0402B222K500NT | FH(风华) | 0402 | 0.000022000 | 100 | ￥0.005762 | ￥0.58
常规 | C77131 |  | NTC热敏电阻 | 10kΩ 电阻精度:±1% 3380K 编带 | NCP15XH103F03RC | muRata(村田) | 0402 | 0.000015000 | 50 | ￥0.077806 | ￥3.89
常规 | C163478 |  | 贴片电阻 | 厚膜电阻 22.1kΩ ±1% 62.5mW 编带 | RC0402FR-0722K1L | YAGEO(国巨) | 0402 | 0.000009000 | 100 | ￥0.003984 | ￥0.40
常规 | C7471880 |  | 贴片型铝电解电容 | 150uF ±20% 35V 编带 | 189RV0018 | KNSCHA(科尼盛) | SMD,D6.3xL7.7mm | 0.000638400 | 10 | ￥0.268320 | ￥2.68
常规 | C879560 |  | 位置传感器 | 零延迟磁角位置传感器IC 管装 | MT6816CT-ACD | MagnTek(麦歌恩) | SOP-8 | 0.000150000 | 6 | ￥18.39 | ￥110.34
常规 | C97643 |  | DC-DC电源芯片 | ME3116AM6G 编带 | ME3116AM6G | MICRONE(南京微盟) | SOT-23-6 | 0.000055000 | 10 | ￥0.8689 | ￥8.69
常规 | C26083 |  | 贴片电阻 | 1MΩ ±1% 62.5mW 厚膜电阻 编带 | 0402WGF1004TCE | UNI-ROYAL(厚声) | 0402 | 0.000009000 | 100 | ￥0.003249 | ￥0.32
常规 | C6568 |  | USB芯片 | CP2102-GMR 编带 | CP2102-GMR | SILICON LABS(芯科) | WQFN-28-EP(5x5) | 0.000145000 | 1 | ￥12.84 | ￥12.84
常规 | C726872 |  | 静电和浪涌保护(TVS/ESD) | SMBJ28CA 编带 | SMBJ28CA | TWGMC(台湾迪嘉) | SMB | 0.000152000 | 10 | ￥0.211792 | ￥2.12
常规 | C11702 |  | 贴片电阻 | 1kΩ ±1% 62.5mW 厚膜电阻 编带 | 0402WGF1001TCE | UNI-ROYAL(厚声) | 0402 | 0.000009000 | 100 | ￥0.003136 | ￥0.31
常规 | C561517 |  | 轻触开关 | 4*3*2mm 立贴 轻触开关 编带 | TS-1185-B-A-B-A | XKB Connectivity(中国星坤) | SMD | 0.000140000 | 20 | ￥0.357936 | ￥7.16
常规 | C7371905 |  | 发光二极管/LED | XL-1608PGC-06 编带 | XL-1608PGC-06 | XINGLIGHT(成兴光) | 0603 | 0.000020170 | 50 | ￥0.054250 | ￥2.71
常规 | C25752 |  | 贴片电阻 | 12kΩ ±1% 62.5mW 厚膜电阻 编带 | 0402WGF1202TCE | UNI-ROYAL(厚声) | 0402 | 0.000009000 | 100 | ￥0.003137 | ￥0.31
常规 | C25871 |  | 贴片电阻 | 1.8kΩ ±1% 62.5mW 厚膜电阻 编带 | 0402WGF1801TCE | UNI-ROYAL(厚声) | 0402 | 0.000009000 | 100 | ￥0.003299 | ￥0.33
常规 | C60491 |  | 贴片电阻 | 厚膜电阻 100kΩ ±1% 62.5mW 编带 | RC0402FR-07100KL | YAGEO(国巨) | 0402 | 0.000009000 | 100 | ￥0.003330 | ￥0.33
常规 | C60490 |  | 贴片电阻 | 厚膜电阻 10kΩ ±1% 62.5mW 编带 | RC0402FR-0710KL | YAGEO(国巨) | 0402 | 0.000009000 | 100 | ￥0.003197 | ￥0.32
常规 | C9002 |  | 无源晶振 | 12MHz ±10ppm 20pF YSX321SL 编带 | X322512MSB4SI | YXC(扬兴晶振) | SMD3225-4P | 0.000047000 | 10 | ￥0.372347 | ￥3.72
常规 | C17168 |  | 贴片电阻 | 0Ω ±1% 62.5mW 厚膜电阻 编带 | 0402WGF0000TCE | UNI-ROYAL(厚声) | 0402 | 0.000009000 | 100 | ￥0.003049 | ￥0.30
常规 | C15525 |  | 贴片电容(MLCC) | 10uF ±20% 6.3V 编带 | CL05A106MQ5NUNC | SAMSUNG(三星) | 0402 | 0.000016500 | 100 | ￥0.030332 | ￥3.03
常规 | C1554 |  | 贴片电容(MLCC) | 20pF ±5% 50V 编带 | 0402CG200J500NT | FH(风华) | 0402 | 0.000022000 | 100 | ￥0.006676 | ￥0.67
常规 | C7420331 |  | 肖特基二极管 | 电压:40V 电流:1A 编带 | B5819WS | 宏迦橙 | SOD-323 | 0.000029000 | 50 | ￥0.073235 | ￥3.66
常规 | C25905 |  | 贴片电阻 | 5.1kΩ ±1% 62.5mW 厚膜电阻 编带 | 0402WGF5101TCE | UNI-ROYAL(厚声) | 0402 | 0.000009000 | 100 | ￥0.003127 | ￥0.31
常规 | C25087 |  | 贴片电阻 | 200Ω ±1% 62.5mW 厚膜电阻 编带 | 0402WGF2000TCE | UNI-ROYAL(厚声) | 0402 | 0.000009000 | 100 | ￥0.003063 | ￥0.31
常规 | C22452 |  | 肖特基二极管 | 电压:40V 电流:5A 编带 | SS54 | MDD | SMA(DO-214AC) | 0.000094000 | 10 | ￥0.240837 | ￥2.41
常规 | C25900 |  | 贴片电阻 | 4.7kΩ ±1% 62.5mW 厚膜电阻 编带 | 0402WGF4701TCE | UNI-ROYAL(厚声) | 0402 | 0.000009000 | 100 | ￥0.003081 | ￥0.31
常规 | C7429528 |  | 线对板/线对线连接器 | 1x6P 间距:1.5mm 直插 系列:ZH 袋装 | ZX-ZH1.5-ZZ6P | Megastar(兆星) | 插件,P=1.5mm | 0.000194400 | 10 | ￥0.201855 | ￥2.02
常规 | C501945 |  | 功率电感 | 6.8uH ±20% 870mA 编带 | VLS201612HBX-6R8M-1 | TDK | 0806 | 0.000011000 | 20 | ￥0.350391 | ￥7.01
常规 | C193707 |  | 无线收发芯片 | 集成2.4GHz WIFI和蓝牙的模组 编带 | ESP32-PICO-D4 | ESPRESSIF(乐鑫) | QFN-48-EP(7x7) | 0.000310000 | 1 | ￥23.01 | ￥23.01
常规 | C306862 |  | 场效应管(MOSFET) | P沟道 耐压:30V 电流:4.2A 编带 | AO3401A | BORN(伯恩半导体) | SOT-23 | 0.000032000 | 10 | ￥0.249179 | ￥2.49
常规 | C3293144 |  | 拨码开关 | 4位 1.27mm间距贴片型 KE拨码开关 编带 | DSHP04TSGER | 康深 | SMD-8P,5.4x6.6mm | 0.000350000 | 6 | ￥2.77 | ￥16.62
常规 | C14445 |  | 贴片电容(MLCC) | 1uF ±10% 10V 编带 | CL05A105KP5NNNC | SAMSUNG(三星) | 0402 | 0.000016500 | 100 | ￥0.011230 | ￥1.12
常规 | C545417 |  | 电机驱动芯片 | TB67H450FNG,EL 编带 | TB67H450FNG,EL | TOSHIBA(东芝) | SOIC-8 | 0.000180000 | 6 | ￥3.25 | ￥19.50
常规 | C347475 |  | 场效应管(MOSFET) | N沟道 耐压:30V 电流:5.8A 编带 | AO3400A | UMW(友台半导体) | SOT-23 | 0.000033000 | 20 | ￥0.172511 | ￥3.45
常规 | C7429534 |  | 线对板/线对线连接器 | 1x3P 间距:1.5mm 弯插 系列:ZH 袋装 | ZX-ZH1.5-WZ3P | Megastar(兆星) | 弯插,P=1.5mm | 0.000126900 | 20 | ￥0.111244 | ￥2.22
常规 | C325569 |  | 贴片电阻 | 560kΩ 1% 62.5mW 编带 | RMC0402560K1%N | Tyohm(幸亚电阻) | 0402 | 0.000009000 | 100 | ￥0.013263 | ￥1.33
常规 | C78988 |  | DC-DC电源芯片 | SY8089AAAC 编带 | SY8089AAAC | silergy(矽力杰) | SOT-23-5 | 0.000046000 | 5 | ￥1.2206 | ￥6.10
常规 | C25334 |  | 贴片电阻 | 100mΩ ±1% 250mW 厚膜电阻 编带 | 1206W4F100LT5E | UNI-ROYAL(厚声) | 1206 | 0.000030000 | 100 | ￥0.029143 | ￥2.91
常规 | C1546 |  | 贴片电容(MLCC) | 100pF ±5% 50V 编带 | 0402CG101J500NT | FH(风华) | 0402 | 0.000022000 | 100 | ￥0.005566 | ￥0.56
常规 | C59461 |  | 贴片电容(MLCC) | 22uF ±20% 6.3V 编带 | CL10A226MQ8NRNC | SAMSUNG(三星) | 0603 | 0.000045000 | 50 | ￥0.052209 | ￥2.61
常规 | C2146 |  | 三极管(BJT) | NPN 电流:500mA 耐压:25V H档(200-350) 编带 | S8050 J3Y | CJ(江苏长电/长晶) | SOT-23 | 0.000036000 | 50 | ￥0.089660 | ￥4.48
常规 | C720628 |  | USB连接器 | Type-C 母 立贴 编带 | TYPEC-303-ACP16 | XUNPU(讯普) | SMD | 0.000990000 | 1 | ￥3.11 | ￥3.11
常规 | C60474 |  | 贴片电容(MLCC) | 100nF ±10% 16V 编带 | CC0402KRX7R7BB104 | YAGEO(国巨) | 0402 | 0.000012020 | 100 | ￥0.004896 | ￥0.49
常规 | C25079 |  | 贴片电阻 | 120Ω ±1% 62.5mW 厚膜电阻 编带 | 0402WGF1200TCE | UNI-ROYAL(厚声) | 0402 | 0.000009000 | 100 | ￥0.003163 | ￥0.32
常规 | C25890 |  | 贴片电阻 | 3.3kΩ ±1% 62.5mW 厚膜电阻 编带 | 0402WGF3301TCE | UNI-ROYAL(厚声) | 0402 | 0.000009000 | 100 | ￥0.002998 | ￥0.30
常规 | C150761 |  | 三极管(BJT) | 耐压:45V 电流:100mA 2个NPN 编带 | BC847BVC-7 | DIODES(美台) | SOT-563 | 0.000027000 | 5 | ￥0.410115 | ￥2.05
常规 | C280577 |  | 功率电感 | 2.2uH ±20% 3.3A 编带 | MHCD252012A-2R2M-A8S | chilisin(奇力新) | SMD | 0.000063000 | 10 | ￥0.228092 | ￥2.28
常规 | C7429537 |  | 线对板/线对线连接器 | 1x6P 间距:1.5mm 弯插 系列:ZH 袋装 | ZX-ZH1.5-WZ6P | Megastar(兆星) | 弯插,P=1.5mm | 0.000215000 | 10 | ￥0.214088 | ￥2.14
常规 | C17888 |  | 贴片电阻 | 0Ω ±1% 250mW 厚膜电阻 编带 | 1206W4F0000T5E | UNI-ROYAL(厚声) | 1206 | 0.000030000 | 100 | ￥0.019218 | ￥1.92
订货 | C194087 |  | 贴片型铝电解电容 | 220uF ±20% 25V 管装 | UUN1E221MNQ1ZD | Nichicon(尼吉康) | SMD | 0.002700000 | 2 | ￥2.49 | ￥4.98
订货 | C8304 |  | 单片机(MCU/MPU/SOC) | STM32F103CBT6 托盘 | STM32F103CBT6 | ST(意法半导体) | LQFP-48(7x7) | 0.001100000 | 6 | ￥10.56 | ￥63.36

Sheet: 其它
内容 | 型号 | 数量 | 链接 | 选项2 | 说明
42 电机 | l=40 | 3 | 42步进电机带磁柱孔马达两相四线雕刻机写字机闭环加装3D打印配件-淘宝网 (taobao.com) (https://item.taobao.com/item.htm?_u=623g2a9g4c7e&id=682797640293&spm=a1z09.2.0.0.3e262e8dTKGxhg)
35 电机 | l=28 | 2 | 35步进电机带磁柱孔马达两相四线雕刻机写字机闭环加装3D打印配件-淘宝网 (taobao.com) (https://item.taobao.com/item.htm?_u=623g2a9g5624&id=723690490192&spm=a1z09.2.0.0.3e262e8dTKGxhg)
J6 35电机 | l=20 | 1 | 德川35步进电机套装 雕刻机模大扭矩 电动小马达精密行星减速机器 (taobao.com) (https://buyertrade.taobao.com/trade/detail/tradeSnap.htm?tradeID=3833501796703004002&snapShot=true)
减速器 | mini11 | 4 | https://item.taobao.com/item.htm?_u=d23g2a9g3be8&id=680325492406&spm=a1z09.2.0.0.33632e8dxUv9b1
减速器 | mini8 | 1 | https://item.taobao.com/item.htm?_u=d23g2a9g3be8&id=680325492406&spm=a1z09.2.0.0.33632e8dxUv9b1
同步轮 | 20齿内孔5mm外径18 | 6 | https://item.taobao.com/item.htm?spm=a1z09.2.0.0.19b12e8dfRIPU3&id=625483500699&_u=a3jnrl7adc93
同步皮带 | 已经实测130X2 150X1 | 1 | https://item.taobao.com/item.htm?spm=a1z09.2.0.0.19b12e8dfRIPU3&id=626759355655&_u=a3jnrl7aa476
电源开关 | 开孔直径：16mm，12-24v | 1 | https://item.taobao.com/item.htm?spm=a1z09.2.0.0.6dcd2e8dgKFAl1&id=589544046782&_u=93jnrl7aceb2
DC电源插座 | DC5.5*2.5mm，10cm，插座带线 | 1 | https://item.taobao.com/item.htm?spm=a1z09.2.0.0.6dcd2e8dgKFAl1&id=679108658727&_u=93jnrl7a3b6f
电源 | 24v 6a | 1 | 全新原装雅达机芯24V6A电源适配器 24V5A净水器监控显示器LED直充-淘宝网 (taobao.com) (https://item.taobao.com/item.htm?_u=723g2a9gcd88&id=529020860643&spm=a1z09.2.0.0.3e262e8dTKGxhg) | https://item.taobao.com/item.htm?id=663983891997&ns=1&abbucket=18 (https://item.taobao.com/item.htm?spm=a21n57.1.0.0.61f5523c45uFiR&id=663983891997&ns=1&abbucket=18) | 选项1不发货了，临时选了这个，送母头
6pin排线 | zh1.5mm 50CM(定做) 6P-22AWG | 1 | https://detail.tmall.com/item.htm?_u=93jnrl7a54c7&id=642559605753&spm=a1z09.2.0.0.6dcd2e8dgKFAl1 | https://detail.tmall.com/item.htm?_u=ukdf1tc9c6&id=635056127519&skuId=4710932887411
6pin排线 | zh1.5mm 30CM(定做) 6P-22AWG | 6 | https://detail.tmall.com/item.htm?_u=93jnrl7a54c7&id=642559605753&spm=a1z09.2.0.0.6dcd2e8dgKFAl1 |  | 然后买了上面的自己做端子
圆柱销 | 5X35 | 4 | https://detail.tmall.com/item.htm?_u=723g2a9g8399&id=617042322309&spm=a1z09.2.0.0.3e262e8dTKGxhg
轴承 | 5X13X4 | 4 | 迷你微型轴承小内径1 1.5 2 2.5 3 4 5 6 7 8 9mm高速模型DIY精密-tmall.com天猫 (https://detail.tmall.com/item.htm?_u=623g2a9g123f&id=611796709407&spm=a1z09.2.0.0.3e262e8dTKGxhg)
轴承 | 5X10X4 | 1 | https://detail.tmall.com/item.htm?id=611796709407&spm=a1z09.2.0.0.4e6e2e8doarR0H&_u=d23g2a9g3c7e
LED灯 | 505 | 1 | https://item.taobao.com/item.htm?_u=723g2a9g35a9&id=686018450822&spm=a1z09.2.0.0.3e262e8dTKGxhg
螺丝安装下图买即可

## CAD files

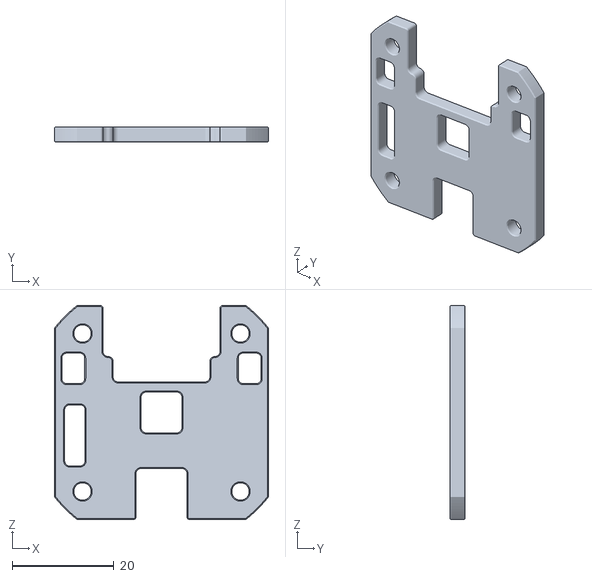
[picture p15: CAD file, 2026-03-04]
4.Model/Dummy V2 版本 视频款/3D打印STL文件/42PCB外壳A.stl
42.0 x 3.00 x 42.0

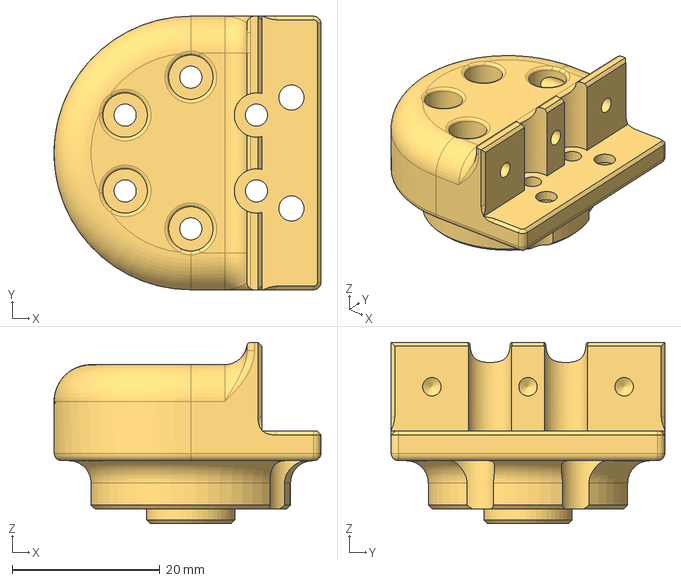
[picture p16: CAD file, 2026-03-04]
4.Model/Dummy V2 版本 视频款/CNC加工STEP文件/J5A.step
36.1 x 37.0 x 24.5 mm

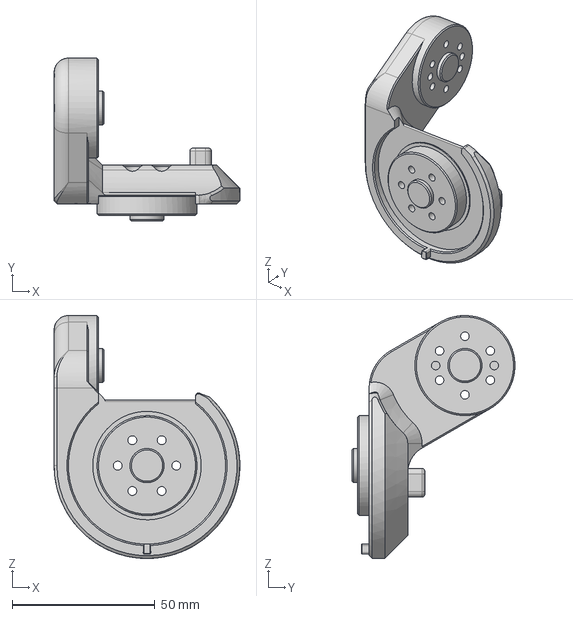
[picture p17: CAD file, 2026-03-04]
4.Model/Dummy V2 版本 视频款/改版/J1改版.step
65.0 x 57.0 x 85.0 mm

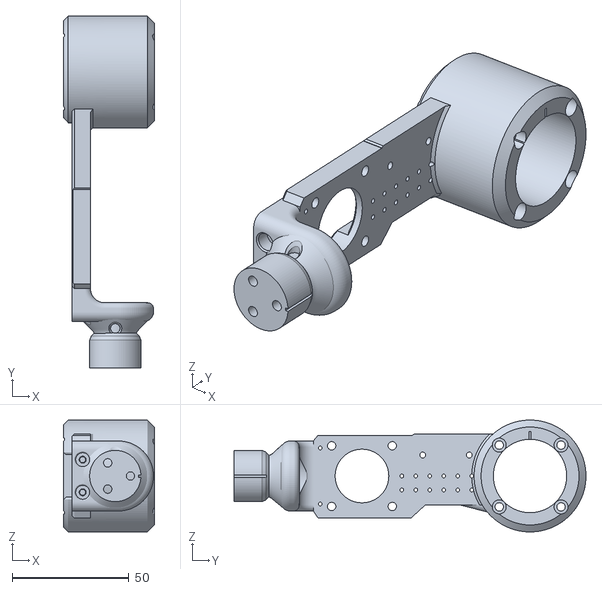
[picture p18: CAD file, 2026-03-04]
4.Model/木子晓汶版本3D模型/joint5.stl
39.0 x 151.0 x 48.0

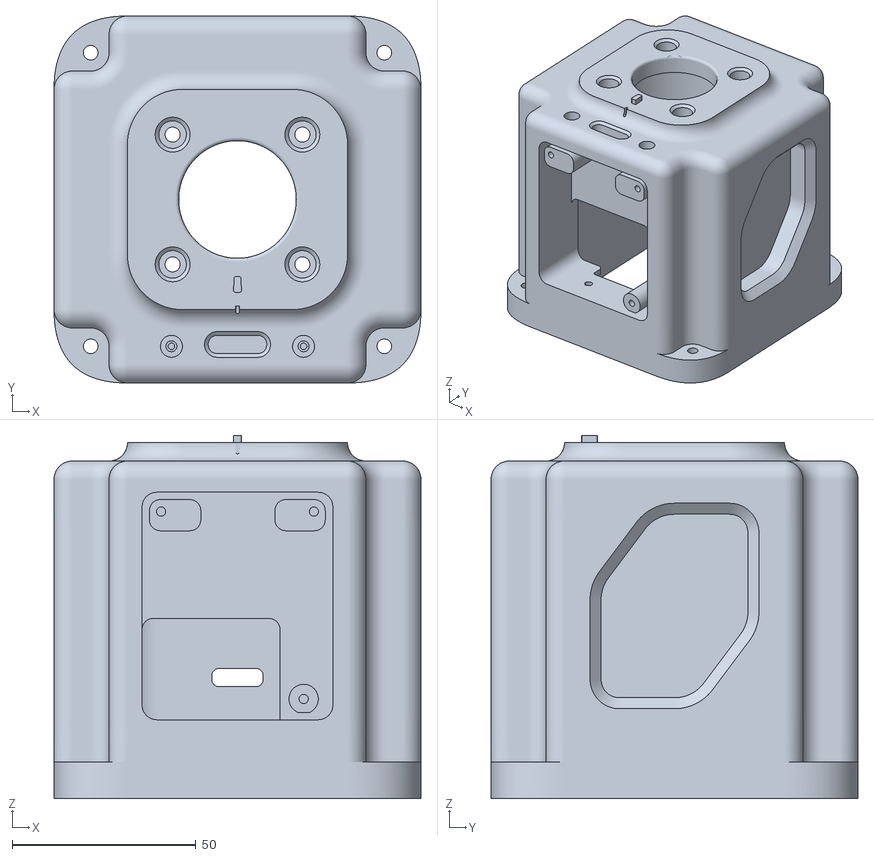
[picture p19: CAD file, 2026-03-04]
4.Model/木子晓汶版本3D模型/latest/base.stl
100.0 x 100.0 x 99.0

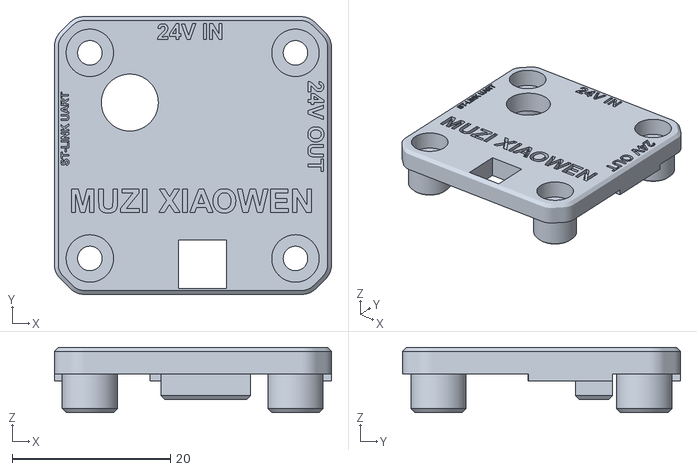
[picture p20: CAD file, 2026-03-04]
4.Model/木子晓汶版本3D模型/m35/motor35-bracket-top-metal.stl
35.0 x 35.1 x 8.25

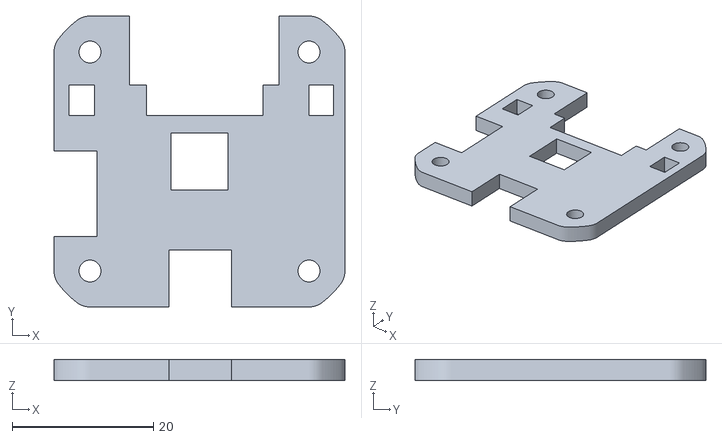
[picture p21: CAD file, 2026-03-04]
4.Model/木子晓汶版本3D模型/m42/motor42-bracket-bot.stl
41.2 x 41.2 x 3.00

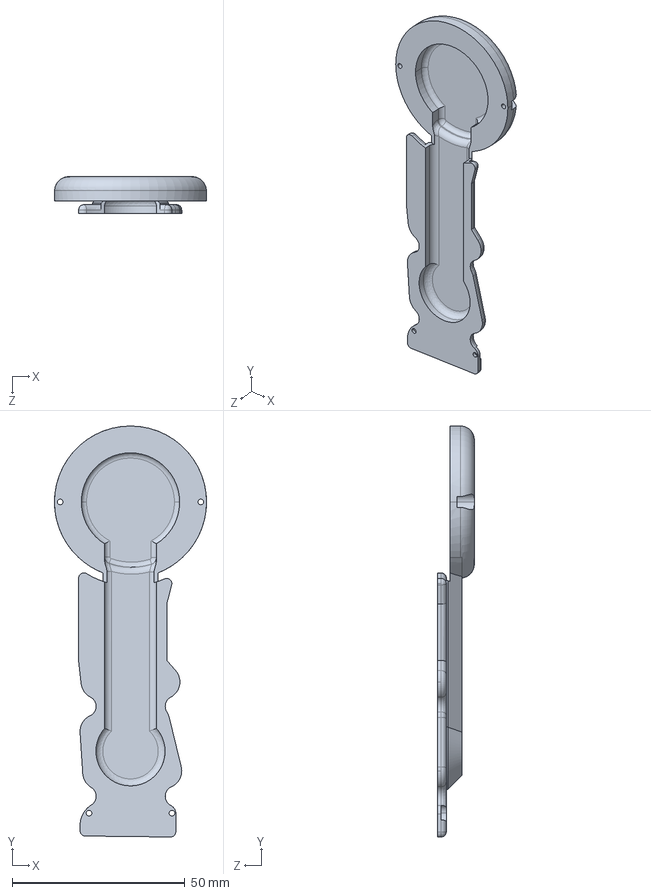
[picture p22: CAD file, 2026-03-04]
4.Model/木子晓汶版本3D模型/Out_stp1/3D/3DJoint5_Dummy v164 v2.STEP
44.0 x 118.9 x 10.6 mm

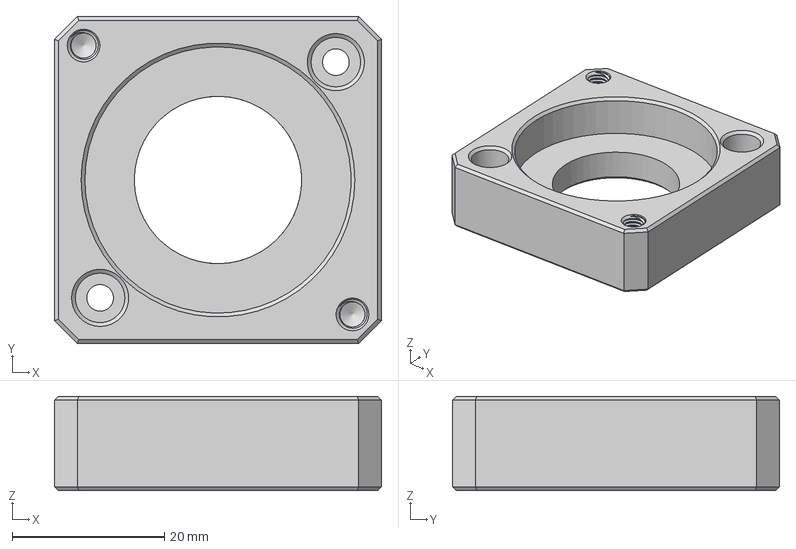
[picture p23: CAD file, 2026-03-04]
4.Model/木子晓汶版本3D模型/Out_stp1/BACK/metal_step/min-11-bra-connection.step
43.0 x 43.0 x 12.4 mm

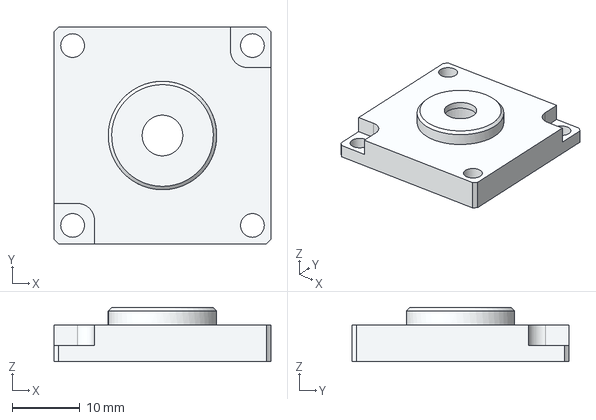
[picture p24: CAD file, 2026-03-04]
4.Model/木子晓汶版本3D模型/Out_stp1/BACK/metal_step/mini8-cover1105/mini8-cover1105.step
32.0 x 32.0 x 8.00 mm

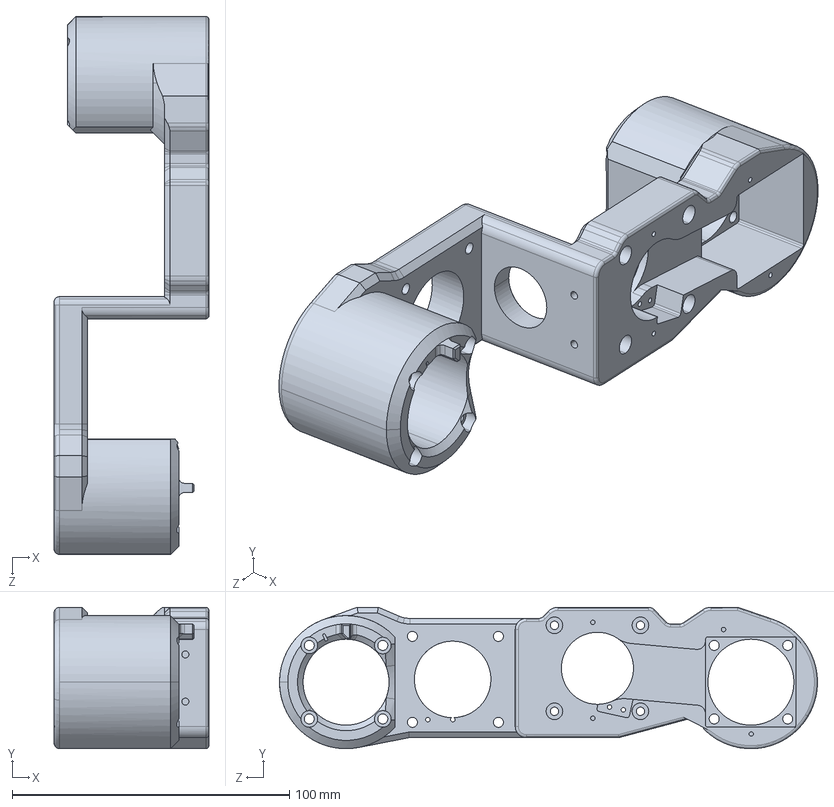
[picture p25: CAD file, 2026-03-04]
4.Model/木子晓汶版本3D模型/Out_stp1/CNC/Joint2 & Joint3_Dummy v164 v1.STEP
55.9 x 51.0 x 194.0 mm

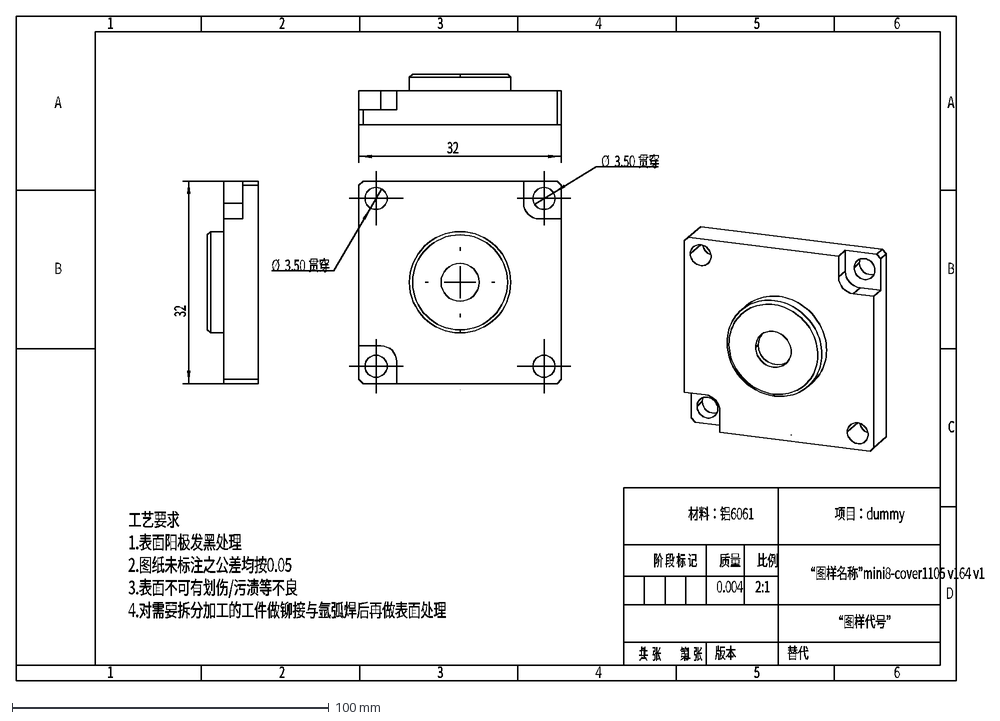
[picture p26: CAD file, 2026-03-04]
4.Model/木子晓汶版本3D模型/Out_stp1/dxf/mini8-cover1105 v164 v1.DXF
替代
版本
比例
质量
第 张
共 张
阶 段 标 记
“图样代号”
“图样名称”mini8-cover1105 v164 v1
0.004
1
2:1
B
A
D
C
2
5
4
3
6
材料：铝6061
项目：dummy
工艺要求
1.表面阳极发黑处理
2.图纸未标注之公差均按0.05
3.表面不可有划伤/污渍等不良
4.对需要拆分加工的工件做铆接与氩弧焊后再做表面处理
Ø
3.50
贯穿
32

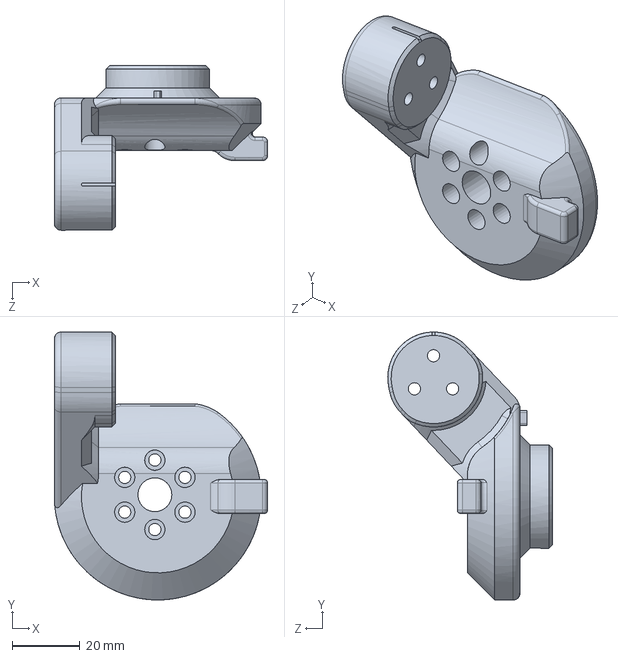
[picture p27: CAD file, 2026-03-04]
4.Model/木子晓汶版本3D模型/Out_stp1/src/Joint1_Dummy v164 v1.SLDPRT
62.9 x 79.0 x 48.5 mm

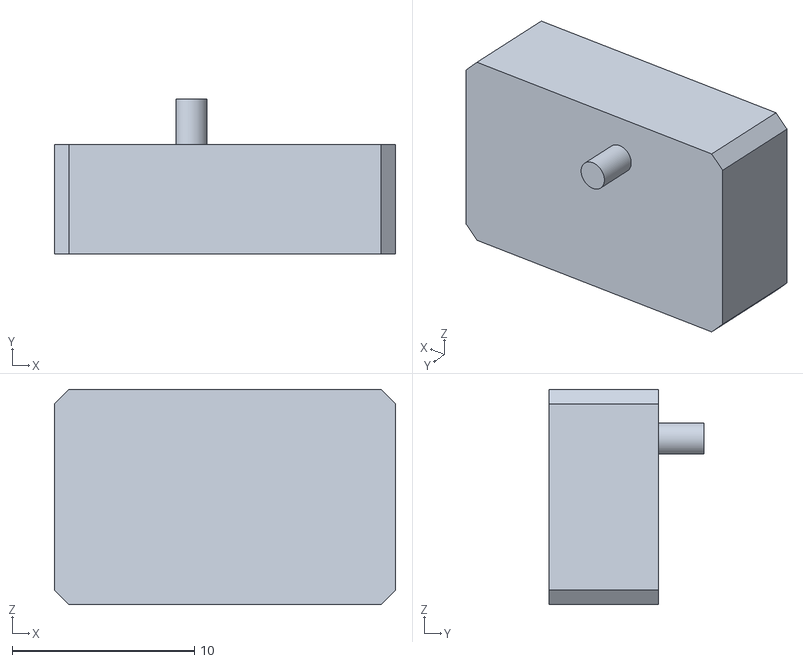
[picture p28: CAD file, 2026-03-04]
4.Model/木子晓汶版本3D模型/ref-controller/contorller-oled-bracket.stl
18.7 x 8.50 x 11.8

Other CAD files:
4.Model/木子晓汶版本3D模型/Out_stp1/BACK/Joint5_Dummy v164 v1.STEP
4.Model/稚晖君原版模型/Motor42-上盖.step
4.Model/Dummy V2 版本 视频款/3D打印STL文件/外壳B.stl
4.Model/Dummy V2 版本 视频款/CNC加工STEP文件/J23.step
4.Model/Dummy V2 版本 视频款/3D打印STL文件/35PCB外壳A.3mf
4.Model/Dummy V2 版本 视频款/3D打印STL文件/35PCB外壳A.stl
4.Model/Dummy V2 版本 视频款/3D打印STL文件/35PCB外壳B.3mf
4.Model/Dummy V2 版本 视频款/3D打印STL文件/35PCB外壳B.stl
4.Model/Dummy V2 版本 视频款/3D打印STL文件/42PCB外壳B.stl
4.Model/Dummy V2 版本 视频款/3D打印STL文件/J1.stl
4.Model/Dummy V2 版本 视频款/3D打印STL文件/J2J3.stl
4.Model/Dummy V2 版本 视频款/3D打印STL文件/J4.stl
4.Model/Dummy V2 版本 视频款/3D打印STL文件/J4法兰盘.stl
4.Model/Dummy V2 版本 视频款/3D打印STL文件/J5A.stl
4.Model/Dummy V2 版本 视频款/3D打印STL文件/J5B.stl
4.Model/Dummy V2 版本 视频款/3D打印STL文件/J5法兰盘.stl
4.Model/Dummy V2 版本 视频款/3D打印STL文件/J6.stl
4.Model/Dummy V2 版本 视频款/3D打印STL文件/基座.3mf
4.Model/Dummy V2 版本 视频款/3D打印STL文件/基座.stl
4.Model/Dummy V2 版本 视频款/3D打印STL文件/基座底板.3mf
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

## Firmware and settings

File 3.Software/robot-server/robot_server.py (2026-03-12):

#!/usr/bin/env python3
"""
Dummy X Robot Arm — FastAPI HTTP/WebSocket server

Bridges the Fibre USB protocol to a REST API callable from Node.js (or any HTTP client).

Usage:
    pip3 install fastapi uvicorn
    python3 robot_server.py          # real hardware via USB
    python3 robot_server.py --sim    # simulation mode (no hardware needed)
    SIM=1 python3 robot_server.py    # same, via env var

Node.js example:
    const res = await fetch('http://localhost:3001/robot/move_j', {
        method: 'POST',
        headers: { 'Content-Type': 'application/json' },
        body: JSON.stringify({ j1: 0, j2: 0, j3: 90, j4: 0, j5: 0, j6: 0 })
    });
    const data = await res.json();  // { "ok": true }

Interactive API docs (auto-generated):
    http://127.0.0.1:3001/docs
"""

import sys
import os
import asyncio
import time
import threading
import json
import re
import math
from datetime import datetime, timezone
from pathlib import Path
from contextlib import asynccontextmanager
from fastapi import FastAPI, WebSocket, WebSocketDisconnect, HTTPException
from fastapi.middleware.cors import CORSMiddleware
from fastapi.responses import Response
from pydantic import BaseModel
from typing import Optional
from ik_solver import solve_ik_batch, solve_ik

# ── Simulation mode flag ──────────────────────────────────────────────────────
SIM_MODE = "--sim" in sys.argv or os.environ.get("SIM", "").lower() in ("1", "true", "yes")

# ── Real hardware import (skipped in sim mode) ────────────────────────────────
if not SIM_MODE:
    sys.path.insert(0, os.path.join(os.path.dirname(__file__), '..', 'CLI-Tool'))
    import fibre


# ══════════════════════════════════════════════════════════════════════════════
# Mock / Simulation layer
# Mirrors the exact object interface that the real fibre USB device exposes,
# so every endpoint above works identically in sim mode.
# ══════════════════════════════════════════════════════════════════════════════

# Joint config mirrors dummy_robot.cpp constructor
_JOINT_CFG = [
    # (reduction, angle_min, angle_max)
    (30, -170.0,  170.0),   # J1 – base rotation
    (30,  -73.0,   90.0),   # J2 – shoulder
    (30,   35.0,  180.0),   # J3 – elbow
    (24, -180.0,  180.0),   # J4 – wrist roll
    (30, -120.0,  120.0),   # J5 – wrist pitch
    (50, -720.0,  720.0),   # J6 – wrist yaw
]

_HOME_POSE   = [0.0,   0.0,  90.0, 0.0, 0.0, 0.0]
_REST_POSE   = [0.0, -73.0, 180.0, 0.0, 0.0, 0.0]
_Z_HOME_POSE = [0.0, -45.0, 140.0, 0.0, 0.0, 0.0]  # lower arm -45°, upper arm ~horizontal
_DEFAULT_SPEED_DEG_S = 30.0   # degrees per second


class MockJoint:
    """
    Simulates one CtrlStepMotor joint.
    Angles move smoothly toward the target at `speed` deg/s.
    The `tick(dt)` method is called by the background simulation loop.
    """

    def __init__(self, index: int):
        reduction, angle_min, angle_max = _JOINT_CFG[index]
        self.index = index
        self.reduction = reduction
        self.angle_min = angle_min
        self.angle_max = angle_max

        self.angle: float = _HOME_POSE[index]      # current angle (deg)
        self._target: float = _HOME_POSE[index]    # goal angle (deg)
        self._speed: float = _DEFAULT_SPEED_DEG_S  # deg/s
        self.enabled: bool = False
        self.temperature: float = 35.0 + index * 1.5   # realistic-ish °C per joint

    # ── Public API (mirrors CtrlStepMotor protocol definitions) ──────────────

    def set_enable(self, enable: bool):
        self.enabled = enable

    def set_position_with_time(self, pos: float, vel: float):
        """Low-level move: pos in motor laps, vel in motor laps/s. No limit check."""
        target_deg = pos / self.reduction * 360.0
        self._target = target_deg

    def do_calibration(self):
        """Simulate ~10 s calibration (instantaneous in sim)."""
        # In real hardware this spins the motor. Here we just note it happened.
        pass

    def get_temperature(self) -> float:
        return self.temperature

    def reboot(self):
        self.enabled = False

    def erase_configs(self):
        pass

    def set_dce_kp(self, val: int): pass
    def set_dce_kv(self, val: int): pass
    def set_dce_ki(self, val: int): pass
    def set_dce_kd(self, val: int): pass

    # ── Simulation internals ──────────────────────────────────────────────────

    def set_target(self, angle_deg: float, speed_deg_s: float):
        """Called by MockRobotInner to command a safe, limit-checked move."""
        self._target = max(self.angle_min, min(self.angle_max, angle_deg))
        self._speed = max(1.0, speed_deg_s)

    def is_moving(self) -> bool:
        return abs(self._target - self.angle) > 0.05  # 0.05° dead-band

    def tick(self, dt: float):
        """Advance angle toward target. Called at ~50 Hz by the sim loop."""
        delta = self._target - self.angle
        max_step = self._speed * dt
        if abs(delta) <= max_step:
            self.angle = self._target
        else:
            self.angle += max_step * (1.0 if delta > 0 else -1.0)


class MockRobotInner:
    """
    Simulates the `dummy.robot` sub-object.
    Mirrors the Fibre protocol properties exposed by dummy_robot.h.
    """

    def __init__(self):
        self.joint_1 = MockJoint(0)
        self.joint_2 = MockJoint(1)
        self.joint_3 = MockJoint(2)
        self.joint_4 = MockJoint(3)
        self.joint_5 = MockJoint(4)
        self.joint_6 = MockJoint(5)
        self._joints = [
            self.joint_1, self.joint_2, self.joint_3,
            self.joint_4, self.joint_5, self.joint_6,
        ]
        self._speed: float = _DEFAULT_SPEED_DEG_S
        self.enabled: bool = False

    # ── Public API ────────────────────────────────────────────────────────────

    def set_enable(self, enable: bool):
        self.enabled = enable
        for j in self._joints:
            j.set_enable(enable)

    def homing(self):
        """Move all joints to L-pose / home."""
        for i, j in enumerate(self._joints):
            j.set_target(_HOME_POSE[i], self._speed)

    def resting(self):
        """Move all joints to rest/storage pose."""
        for i, j in enumerate(self._joints):
            j.set_target(_REST_POSE[i], self._speed)

    def move_j(self, j1: float, j2: float, j3: float,
               j4: float, j5: float, j6: float):
        """Joint-space move with limit check (mirrors MoveJ in firmware)."""
        targets = [j1, j2, j3, j4, j5, j6]
        valid = all(
            self._joints[i].angle_min <= targets[i] <= self._joints[i].angle_max
            for i in range(6)
        )
        if not valid:
            return  # silently drop, same as firmware
        for i, j in enumerate(self._joints):
            j.set_target(targets[i], self._speed)

    def move_l(self, x: float, y: float, z: float,
               a: float, b: float, c: float):
        """
        Cartesian move — IK not implemented in sim.
        Logs the target; no motion occurs.
        """
        print(f"[SIM] move_l({x:.1f}, {y:.1f}, {z:.1f}, {a:.1f}, {b:.1f}, {c:.1f})"
              " — IK not implemented in sim mode, command ignored.")

    def set_joint_speed(self, speed: float):
        """Set speed (deg/s). Mirrors set_joint_speed in firmware."""
        self._speed = max(1.0, min(100.0, speed))

    def calibrate_home_offset(self):
        """Simulate home-offset calibration: zero all angles."""
        for j in self._joints:
            j.angle = 0.0
            j._target = 0.0

    # ── Simulation internals ──────────────────────────────────────────────────

    def tick(self, dt: float):
        for j in self._joints:
            j.tick(dt)

    def is_moving(self) -> bool:
        return any(j.is_moving() for j in self._joints)


class MockDummy:
    """
    Top-level simulation object — mirrors the fibre `dummy` device handle.
    Exposes `.robot`, `.serial_number`, `.get_temperature()`, `.get_voltage()`.
    """

    def __init__(self):
        self.robot = MockRobotInner()
        self.serial_number = "SIM-001"
        self._voltage: float = 24.1
        self._temperature: float = 42.0

    def get_temperature(self) -> float:
        return self._temperature

    def get_voltage(self) -> float:
        return self._voltage


# ── Global robot connection ───────────────────────────────────────────────────
dummy = None
_sim_task = None      # background simulation loop handle
_stop_requested: bool = False   # set by /robot/stop to interrupt play_sequence

# ── Server mode ───────────────────────────────────────────────────────────────
# high_level (default): only safe motion commands are accessible.
# low_level: additionally exposes tuning and diagnostic commands (DCE params,
#            raw calibration, etc.). Switch deliberately; revert when done.
_server_mode: str = "high_level"

def _check_low_level():
    """Call at the top of any low-level-only endpoint to enforce mode gating."""
    if _server_mode != "low_level":
        raise HTTPException(
            status_code=403,
            detail="This endpoint is only available in low_level mode. "
                   "POST /server/mode {\"mode\": \"low_level\"} to enable."
        )

# ── DCE parameter mirror ──────────────────────────────────────────────────────
# Firmware exposes set_dce_* but no get_dce_* — we mirror values server-side.
# Initialised to firmware defaults (kp=200, kv=80, ki=300, kd=250).
_DCE_DEFAULTS = {"kp": 200, "kv": 80, "ki": 300, "kd": 250}
_dce_params: dict[int, dict] = {n: dict(_DCE_DEFAULTS) for n in range(1, 7)}


class _StopRequested(Exception):
    """Internal signal: raised inside execute_steps when /robot/stop is called."""
    pass


# ── Sequence database ─────────────────────────────────────────────────────────
_SEQ_FILE  = Path(__file__).parent / "sequences.json"
_seq_lock  = threading.Lock()
_sequences: dict = {}   # in-memory cache; flushed to disk on every write

_SEQ_NAME_RE = re.compile(r'^[a-z0-9][a-z0-9_-]{0,63}$')   # lowercase, hyphens, underscores

# ── TCP (Tool Center Point) offset ───────────────────────────────────────────
# When a tool is attached to J6, its tip is `_tool_length_mm` beyond the wrist.
# move_l automatically back-calculates the required wrist position so the TOOL
# TIP lands at the user-specified (x, y, z).  Set to 0.0 when no tool attached.
_tool_length_mm: float = 0.0

def _euler_to_rot(a_deg: float, b_deg: float, c_deg: float):
    """
    Build a 3×3 rotation matrix from ZYX Euler angles (degrees).
    Convention matches firmware: a=roll(X), b=pitch(Y), c=yaw(Z).
    Returns a flat list[9] in row-major order (same as firmware R06 layout).
    """
    a = math.radians(a_deg)
    b = math.radians(b_deg)
    c = math.radians(c_deg)
    ca, sa = math.cos(a), math.sin(a)
    cb, sb = math.cos(b), math.sin(b)
    cc, sc = math.cos(c), math.sin(c)
    # R = Rz(c) @ Ry(b) @ Rx(a)
    return [
        cb*cc,          cc*sa*sb - ca*sc,   ca*cc*sb + sa*sc,
        cb*sc,          ca*cc + sa*sb*sc,   ca*sb*sc - cc*sa,
        -sb,            cb*sa,              ca*cb,
    ]

def _apply_tcp(x: float, y: float, z: float,
               a: float, b: float, c: float):
    """
    Adjust the requested TOOL TIP position (x, y, z) to the required WRIST
    position that the firmware IK should target.

    The tool extends along the local Z-axis of J6.  In world coordinates that
    direction is the third column of the end-effector rotation matrix R:
        offset_world = R × [0, 0, tool_length]
    So wrist_target = tool_tip_target - offset_world.
    """
    if _tool_length_mm == 0.0:
        return x, y, z
    R = _euler_to_rot(a, b, c)
    # Third column of R (local Z axis in world frame) = R[2], R[5], R[8]
    wx = x - R[2] * _tool_length_mm
    wy = y - R[5] * _tool_length_mm
    wz = z - R[8] * _tool_length_mm
    return wx, wy, wz


def _load_sequences():
    """Load sequences from disk into _sequences cache. Called at startup."""
    global _sequences
    if _SEQ_FILE.exists():
        with open(_SEQ_FILE, "r") as f:
            _sequences = json.load(f)
        print(f"✓  Loaded {len(_sequences)} sequence(s) from {_SEQ_FILE.name}")
    else:
        _sequences = {}
        print("✓  No sequences.json found — starting with empty library.")


def _save_sequences():
    """Flush _sequences cache to disk. Must be called inside _seq_lock."""
    with open(_SEQ_FILE, "w") as f:
        json.dump(_sequences, f, indent=2)


def _now_iso() -> str:
    return datetime.now(timezone.utc).strftime("%Y-%m-%dT%H:%M:%SZ")


async def _sim_loop():
    """Background task: ticks the mock robot at ~50 Hz."""
    last = time.monotonic()
    while True:
        await asyncio.sleep(0.02)   # 50 Hz
        now = time.monotonic()
        dt = now - last
        last = now
        if dummy is not None:
            dummy.robot.tick(dt)


@asynccontextmanager
async def lifespan(app: FastAPI):
    global dummy, _sim_task

    if SIM_MODE:
        print("🤖  Simulation mode — no hardware required.")
        dummy = MockDummy()
        _sim_task = asyncio.create_task(_sim_loop())
        print("✓  Mock robot ready.")
    else:
        print("Connecting to robot via USB (timeout 90 s)...")
        loop = asyncio.get_event_loop()
        dummy = await loop.run_in_executor(
            None, lambda: fibre.find_any("usb", timeout=90)
        )
        if dummy is None:
            print("⚠  Robot not found. Endpoints will return 503 until connected.")
        else:
            print("✓  Robot connected.")

    yield

    if _sim_task is not None:
        _sim_task.cancel()
    dummy = None


# Load sequence library on import (before first request)
_load_sequences()


app = FastAPI(
    title="Dummy Robot Arm API",
    version="1.0.0",
    lifespan=lifespan,
    description="Set `SIM=1` or pass `--sim` to start without hardware.",
)
app.add_middleware(
    CORSMiddleware, allow_origins=["*"], allow_methods=["*"], allow_headers=["*"]
)


def get_robot():
    if dummy is None:
        raise HTTPException(status_code=503, detail="Robot not connected")
    # Verify the fibre object still has a live .robot attribute.
    # This can go missing if USB disconnects after the server starts.
    if not SIM_MODE and not hasattr(dummy, "robot"):
        raise HTTPException(
            status_code=503,
            detail="Robot USB connection lost — please reconnect and restart the server",
        )
    return dummy


# ── Request models ────────────────────────────────────────────────────────────
class EnableBody(BaseModel):
    enable: bool


class MoveJBody(BaseModel):
    j1: float
    j2: float
    j3: float
    j4: float
    j5: float
    j6: float


class MoveLBody(BaseModel):
    x: float
    y: float
    z: float
    a: float
    b: float
    c: float


class SetToolBody(BaseModel):
    tool_length_mm: float   # distance from J6 flange to tool tip, in mm. 0 = no tool.


class SetModeBody(BaseModel):
    mode: str  # "high_level" or "low_level"


class DceParamsBody(BaseModel):
    kp: Optional[int] = None  # position error → direct output (stiffness)
    kv: Optional[int] = None  # velocity error → integral (dynamic damping memory)
    ki: Optional[int] = None  # position error → integral (holds against gravity)
    kd: Optional[int] = None  # velocity error → direct output (damping)


class MoveLPathBody(BaseModel):
    poses: list[list[float]]  # list of [x,y,z,a,b,c] waypoints (mm + degrees)
    step_delay_ms: float = 80.0  # milliseconds between MoveJ commands (default 80ms)
    tcp_apply: bool = True        # apply active tool TCP offset to each waypoint


class SpeedBody(BaseModel):
    speed: float


class SoftMoveBody(BaseModel):
    speed:            float = 15.0   # deg/s — default slower for safety
    settle_threshold: float = 0.5    # degrees — "close enough" to target
    settle_timeout:   float = 20.0   # max seconds to wait for settling


class CreateSequenceBody(BaseModel):
    name:             str
    description:      str   = ""
    speed:            float = 20.0
    settle_threshold: float = 0.5
    settle_timeout:   float = 15.0
    steps:            list  # list of SequenceStep-compatible dicts


class UpdateSequenceBody(BaseModel):
    description:      str   | None = None
    speed:            float | None = None
    settle_threshold: float | None = None
    settle_timeout:   float | None = None
    steps:            list  | None = None   # None = keep existing steps


class PlaySequenceOverrideBody(BaseModel):
    speed:            float | None = None   # override saved speed
    settle_threshold: float | None = None
    settle_timeout:   float | None = None


class JointPosBody(BaseModel):
    pos: float
    vel: float


# ── Helper ────────────────────────────────────────────────────────────────────
def get_joint(n: int):
    if n < 1 or n > 6:
        raise HTTPException(status_code=400, detail="Joint number must be 1-6")
    return getattr(get_robot().robot, f"joint_{n}")


# ── Robot-level endpoints ─────────────────────────────────────────────────────
@app.post("/robot/enable")
def set_enable(body: EnableBody):
    get_robot().robot.set_enable(body.enable)
    return {"ok": True}


@app.post("/robot/homing")
def soft_home(body: SoftMoveBody = SoftMoveBody()):
    """
    Soft home: moves the arm to the home pose [0, 0, 90, 0, 0, 0] using
    move_j + settle detection. Replaces the buggy firmware homing() which
    cannot reliably detect completion.

    - Clears any previous stop flag (explicit command = intentional move).
    - Motors are enabled automatically.
    - Default speed: 15 °/s (safe, gentle).
    - Waits until all joints settle within 0.5° of target (or timeout).
    - Respects /robot/stop: exits settle loop early and returns stopped=true.
    """
    global _stop_requested
    _stop_requested = False   # explicit command clears any prior stop

    d = get_robot()
    r = d.robot
    r.set_enable(True)
    r.set_joint_speed(body.speed)

    target_phys = list(_HOME_POSE)   # [0, 0, 90, 0, 0, 0]
    r.move_j(*target_phys)
    target_enc = _physical_to_encoder(target_phys)
    settle_s = _wait_for_settle(r, target_enc, body.settle_threshold, body.settle_timeout,
                                check_stop=True)

    if _stop_requested:
        phys_now = _encoder_to_physical(_read_angles(r))
        return {
            "ok":        False,
            "stopped":   True,
            "frozen_at": [round(a, 2) for a in phys_now],
            "settle_s":  round(settle_s, 2),
        }

    return {
        "ok":       True,
        "pose":     "home",
        "target":   target_phys,
        "angles":   [round(a, 2) for a in _encoder_to_physical(_read_angles(r))],
        "settle_s": round(settle_s, 2),
    }


@app.post("/robot/z_home")
def soft_z_home(body: SoftMoveBody = SoftMoveBody()):
    """
    Z-home: a natural resting pose that looks like a Z from the side.
    Lower arm tilted back at -45° (J2), upper arm approximately horizontal (J3=140°).
    Formula: upper arm angle from horizontal = J2 + J3 - 90°  → -45 + 140 - 90 = 5° (slightly above horizontal)

    - Clears any previous stop flag (explicit command = intentional move).
    - Motors are enabled automatically.
    - Default speed: 15 °/s (safe, gentle).
    - Waits until all joints settle within 0.5° of target (or timeout).
    - Respects /robot/stop: exits settle loop early and returns stopped=true.
    """
    global _stop_requested
    _stop_requested = False

    d = get_robot()
    r = d.robot
    r.set_enable(True)
    r.set_joint_speed(body.speed)

    target_phys = list(_Z_HOME_POSE)   # [0, 0, 60, 0, 0, 0]
    r.move_j(*target_phys)
    target_enc = _physical_to_encoder(target_phys)
    settle_s = _wait_for_settle(r, target_enc, body.settle_threshold, body.settle_timeout,
                                check_stop=True)

    if _stop_requested:
        phys_now = _encoder_to_physical(_read_angles(r))
        return {
            "ok":        False,
            "stopped":   True,
            "frozen_at": [round(a, 2) for a in phys_now],
            "settle_s":  round(settle_s, 2),
        }

    return {
        "ok":       True,
        "pose":     "z_home",
        "target":   target_phys,
        "angles":   [round(a, 2) for a in _encoder_to_physical(_read_angles(r))],
        "settle_s": round(settle_s, 2),
    }


@app.post("/robot/resting")
def soft_rest(body: SoftMoveBody = SoftMoveBody()):
    """
    Soft rest: moves the arm to the rest/storage pose [0, -73, 180, 0, 0, 0]
    using move_j + settle detection. Replaces the buggy firmware resting()
    which cannot reliably detect completion.

    - Clears any previous stop flag (explicit command = intentional move).
    - Motors are enabled automatically.
    - Default speed: 15 °/s (safe, gentle).
    - Waits until all joints settle within 0.5° of target (or timeout).
    - Respects /robot/stop: exits settle loop early and returns stopped=true.
    """
    global _stop_requested
    _stop_requested = False   # explicit command clears any prior stop

    d = get_robot()
    r = d.robot
    r.set_enable(True)
    r.set_joint_speed(body.speed)

    target_phys = list(_REST_POSE)   # [0, -73, 180, 0, 0, 0]
    r.move_j(*target_phys)
    target_enc = _physical_to_encoder(target_phys)
    settle_s = _wait_for_settle(r, target_enc, body.settle_threshold, body.settle_timeout,
                                check_stop=True)

    if _stop_requested:
        phys_now = _encoder_to_physical(_read_angles(r))
        return {
            "ok":        False,
            "stopped":   True,
            "frozen_at": [round(a, 2) for a in phys_now],
            "settle_s":  round(settle_s, 2),
        }

    return {
        "ok":       True,
        "pose":     "rest",
        "target":   target_phys,
        "angles":   [round(a, 2) for a in _encoder_to_physical(_read_angles(r))],
        "settle_s": round(settle_s, 2),
    }
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

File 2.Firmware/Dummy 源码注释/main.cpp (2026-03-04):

#include "common_inc.h"


// On-board Screen, can choose from hi2c2 or hi2c0(soft i2c)
SSD1306 oled(&hi2c0);
// On-board Sensor, used hi2c1
MPU6050 mpu6050(&hi2c1);
// 5 User-Timers, can choose from htim7/htim10/htim11/htim13/htim14
Timer timerCtrlLoop(&htim7, 200);
// 2x2-channel PWMs, used htim9 & htim12, each has 2-channel outputs
PWM pwm(21000, 21000);

RGB rgb(0);
// Robot instance
DummyRobot dummy(&hcan1);


/* Thread Definitions -----------------------------------------------------*/
osThreadId_t controlLoopFixUpdateHandle;
//controlLoopFixUpdateHandle 是该线程的句柄，用于标识和操作线程。
void ThreadControlLoopFixUpdate(void* argument)
{
    for (;;)
    {
        // Suspended here until got Notification.
        ulTaskNotifyTake(pdTRUE, portMAX_DELAY);
        //ulTaskNotifyTake(pdTRUE, portMAX_DELAY)）。该线程在没有任务通知时会一直阻塞。

        if (dummy.IsEnabled())
        {
            // Send control command to Motors & update Joint states
            //一旦接收到任务通知，线程首先检查机器人是否启用
            switch (dummy.commandMode)
            {
                case DummyRobot::COMMAND_TARGET_POINT_SEQUENTIAL:
                case DummyRobot::COMMAND_TARGET_POINT_INTERRUPTABLE:
                case DummyRobot::COMMAND_CONTINUES_TRAJECTORY:
                    dummy.MoveJoints(dummy.targetJoints);
                    dummy.UpdateJointPose6D();
                    break;
// 如果机器人启用，根据不同的指令模式执行相应的操作：
//如果是 COMMAND_TARGET_POINT_SEQUENTIAL, COMMAND_TARGET_POINT_INTERRUPTABLE, 
//或 COMMAND_CONTINUES_TRAJECTORY，
//则通过调用 dummy.MoveJoints(dummy.targetJoints) 
//发送控制命令到电机，并更新关节状态和六自由度姿态

                case DummyRobot::COMMAND_MOTOR_TUNING:
                    dummy.tuningHelper.Tick(10);
                    dummy.UpdateJointPose6D();
                    break;
//如果是 COMMAND_MOTOR_TUNING，
//则调用 dummy.tuningHelper.Tick(10) 执行调谐，
//并更新六自由度姿态。



            }
        } else
        {
            // Just update Joint states
            dummy.UpdateJointAngles();
            dummy.UpdateJointPose6D();
        }
//如果机器人未启用，只会更新关节状态和六自由度姿态。
//ThreadControlLoopUpdate 线程：
//ControlLoopUpdateHandle 是该线程的句柄，用于标识和操作线程。
//线程进入无限循环，在循环中通过 dummy.commandHandler.Pop(osWaitForever) 
//从 dummy.commandHandler 中弹出指令，
//并通过 dummy.commandHandler.ParseCommand() 解析和处理该指令。

        
    }
}


osThreadId_t ControlLoopUpdateHandle;
void ThreadControlLoopUpdate(void* argument)
{
    for (;;)
    {
        dummy.commandHandler.ParseCommand(dummy.commandHandler.Pop(osWaitForever));
    }
}


osThreadId_t oledTaskHandle;
//该函数是一个FreeRTOS线程，用于更新OLED显示屏上的信息。
//在每次循环中，首先获取当前时间戳 t，然后调用mpu6050.Update(true)来获取MPU6050传感器的数据。
//使用oled对象操作OLED显示屏，显示IMU的加速度数据、帧率、关节角度、机器人姿态等信息。
void ThreadOledUpdate(void* argument)
{
    uint32_t t = micros();
    char buf[16];
    char cmdModeNames[4][4] = {"SEQ", "INT", "TRJ", "TUN"};

    for (;;)
    {
        // 获取IMU数据
        mpu6050.Update(true);

        // 清空缓冲区
        oled.clearBuffer();
        // 显示IMU的加速度数据和帧率
        oled.setFont(u8g2_font_5x8_tr);
        oled.setCursor(0, 10);
        oled.printf("IMU:%.3f/%.3f", mpu6050.data.ax, mpu6050.data.ay);
        oled.setCursor(85, 10);
        oled.printf("| FPS:%lu", 1000000 / (micros() - t));
        t = micros();
        // 绘制关节角度信息
        oled.drawBox(0, 15, 128, 3);
        oled.setCursor(0, 30);
        oled.printf(">%3d|%3d|%3d|%3d|%3d|%3d",
                    (int) roundf(dummy.currentJoints.a[0]), (int) roundf(dummy.currentJoints.a[1]),
                    (int) roundf(dummy.currentJoints.a[2]), (int) roundf(dummy.currentJoints.a[3]),
                    (int) roundf(dummy.currentJoints.a[4]), (int) roundf(dummy.currentJoints.a[5]));

        // 绘制机器人姿态信息
        oled.drawBox(40, 35, 128, 24);
        oled.setFont(u8g2_font_6x12_tr);
        oled.setDrawColor(0);
        oled.setCursor(42, 45);
        oled.printf("%4d|%4d|%4d", (int) roundf(dummy.currentPose6D.X),
                    (int) roundf(dummy.currentPose6D.Y), (int) roundf(dummy.currentPose6D.Z));
        oled.setCursor(42, 56);
        oled.printf("%4d|%4d|%4d", (int) roundf(dummy.currentPose6D.A),
                    (int) roundf(dummy.currentPose6D.B), (int) roundf(dummy.currentPose6D.C));
        oled.setDrawColor(1);
        oled.setCursor(0, 45);
        oled.printf("[XYZ]:");
        oled.setCursor(0, 56);
        oled.printf("[ABC]:");
        // 绘制机器人状态信息
        oled.setFont(u8g2_font_10x20_tr);
        oled.setCursor(0, 78);
        if (dummy.IsEnabled())
        {
            for (int i = 1; i <= 6; i++)
                buf[i - 1] = (dummy.jointsStateFlag & (1 << i) ? '*' : '_');
            buf[6] = 0;
            oled.printf("[%s] %s", cmdModeNames[dummy.commandMode - 1], buf);
        } else
        {
            oled.printf("[%s] %s", cmdModeNames[dummy.commandMode - 1], "======");
        }

        // 将缓冲区内容发送到OLED显示屏
        oled.sendBuffer();
    }
    //
//这是一个用于更新OLED显示屏的线程，主要通过读取MPU6050传感器的数据和机器人的状态信息来实现。以下是代码的主要功能和结构解释：
//线程函数 ThreadOledUpdate:
//该函数是一个FreeRTOS线程，用于更新OLED显示屏上的信息。
//在每次循环中，首先获取当前时间戳 t，然后调用mpu6050.Update(true)来获取MPU6050传感器的数据。
//使用oled对象操作OLED显示屏，显示IMU的加速度数据、帧率、关节角度、机器人姿态等信息。
cpp
Copy code
osThreadId_t oledTaskHandle;
void ThreadOledUpdate(void* argument)
{
    uint32_t t = micros();
    char buf[16];
    char cmdModeNames[4][4] = {"SEQ", "INT", "TRJ", "TUN"};

    for (;;)
    {
        // 获取IMU数据
        mpu6050.Update(true);

        // 清空缓冲区
        oled.clearBuffer();
        
        // 显示IMU的加速度数据和帧率
        oled.setFont(u8g2_font_5x8_tr);
        oled.setCursor(0, 10);
        oled.printf("IMU:%.3f/%.3f", mpu6050.data.ax, mpu6050.data.ay);
        oled.setCursor(85, 10);
        oled.printf("| FPS:%lu", 1000000 / (micros() - t));
        t = micros();

        // 绘制关节角度信息
        oled.drawBox(0, 15, 128, 3);
        oled.setCursor(0, 30);
        oled.printf(">%3d|%3d|%3d|%3d|%3d|%3d",
                    (int) roundf(dummy.currentJoints.a[0]), (int) roundf(dummy.currentJoints.a[1]),
                    (int) roundf(dummy.currentJoints.a[2]), (int) roundf(dummy.currentJoints.a[3]),
                    (int) roundf(dummy.currentJoints.a[4]), (int) roundf(dummy.currentJoints.a[5]));

        // 绘制机器人姿态信息
        oled.drawBox(40, 35, 128, 24);
        oled.setFont(u8g2_font_6x12_tr);
        oled.setDrawColor(0);
        oled.setCursor(42, 45);
        oled.printf("%4d|%4d|%4d", (int) roundf(dummy.currentPose6D.X),
                    (int) roundf(dummy.currentPose6D.Y), (int) roundf(dummy.currentPose6D.Z));
        oled.setCursor(42, 56);
        oled.printf("%4d|%4d|%4d", (int) roundf(dummy.currentPose6D.A),
                    (int) roundf(dummy.currentPose6D.B), (int) roundf(dummy.currentPose6D.C));
        oled.setDrawColor(1);
        oled.setCursor(0, 45);
        oled.printf("[XYZ]:");
        oled.setCursor(0, 56);
        oled.printf("[ABC]:");
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

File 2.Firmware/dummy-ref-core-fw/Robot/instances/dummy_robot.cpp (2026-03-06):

#include "communication.hpp"
#include "dummy_robot.h"

inline float AbsMaxOf6(DOF6Kinematic::Joint6D_t _joints, uint8_t &_index)
{
    float max = -1;
    for (uint8_t i = 0; i < 6; i++)
    {
        if (abs(_joints.a[i]) > max)
        {
            max = abs(_joints.a[i]);
            _index = i;
        }
    }

    return max;
}


DummyRobot::DummyRobot(CAN_HandleTypeDef* _hcan) :
    hcan(_hcan)
{
    motorJ[ALL] = new CtrlStepMotor(_hcan, 0, false, 1, -180, 180);
    motorJ[1] = new CtrlStepMotor(_hcan, 1, true, 50, -170, 170);
    motorJ[2] = new CtrlStepMotor(_hcan, 2, false, 50, -73, 90);
    motorJ[3] = new CtrlStepMotor(_hcan, 3, false, 50, 35, 180);
    motorJ[4] = new CtrlStepMotor(_hcan, 4, true, 40, -180, 180);
    motorJ[5] = new CtrlStepMotor(_hcan, 5, false, 50, -120, 120);
    motorJ[6] = new CtrlStepMotor(_hcan, 6, false, 50, -720, 720);
    hand = new DummyHand(_hcan, 7);

    dof6Solver = new DOF6Kinematic(0.109f, 0.035f, 0.146f, 0.115f, 0.052f, 0.072f);
}


DummyRobot::~DummyRobot()
{
    for (int j = 0; j <= 6; j++)
        delete motorJ[j];

    delete hand;
    delete dof6Solver;
}


void DummyRobot::Init()
{
    SetCommandMode(DEFAULT_COMMAND_MODE);
    SetJointSpeed(DEFAULT_JOINT_SPEED);
}


void DummyRobot::Reboot()
{
    motorJ[ALL]->Reboot();
    osDelay(500); // waiting for all joints done
    HAL_NVIC_SystemReset();
}

void DummyRobot::MoveJoints(DOF6Kinematic::Joint6D_t _joints)
{
    for (int j = 1; j <= 6; j++)
    {
        motorJ[j]->SetAngleWithVelocityLimit(_joints.a[j - 1] - initPose.a[j - 1],
                                             dynamicJointSpeeds.a[j - 1]);
    }
}


bool DummyRobot::MoveJ(float _j1, float _j2, float _j3, float _j4, float _j5, float _j6)
{
    DOF6Kinematic::Joint6D_t targetJointsTmp(_j1, _j2, _j3, _j4, _j5, _j6);
    bool valid = true;

    for (int j = 1; j <= 6; j++)
    {
        if (targetJointsTmp.a[j - 1] > motorJ[j]->angleLimitMax ||
            targetJointsTmp.a[j - 1] < motorJ[j]->angleLimitMin)
            valid = false;
    }

    if (valid)
    {
        DOF6Kinematic::Joint6D_t deltaJoints = targetJointsTmp - currentJoints;
        uint8_t index;
        float maxAngle = AbsMaxOf6(deltaJoints, index);
        float time = maxAngle * (float) (motorJ[index + 1]->reduction) / jointSpeed;
        for (int j = 1; j <= 6; j++)
        {
            dynamicJointSpeeds.a[j - 1] =
                abs(deltaJoints.a[j - 1] * (float) (motorJ[j]->reduction) / time * 0.1f); //0~10r/s
        }

        jointsStateFlag = 0;
        targetJoints = targetJointsTmp;

        return true;
    }

    return false;
}
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

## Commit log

2026-03-04 Initial commit with J2 direction fix
    [35PCB外壳A.3mf, 35PCB外壳A.stl, 35PCB外壳B.3mf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]
2026-03-06 Fix motor direction flags and reduction ratios for our hardware
    - Fix inverseDirection: J2=false, J3=false (vendor vs self-built motor
    driver firmware difference), J4=true, J5=false, J6=false (35-motor
    coil wiring difference from reference design). J1 unchanged (true).
    - Fix reduction ratios: all joints use 50:1 gearboxes (was 30 for
    J1-J3/J5, 24 for J4). J4 effective ratio is 40 (50×0.8 belt coupling).
    J6 was already correct at 50.
    - Increase protocol resend timeout from 5s to 60s to accommodate
    slower movements with 50:1 gearing.
    - Add learning docs: calibration troubleshooting, joint direction
    verification guide, and agent usage guide.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
    [dummy_robot.cpp, protocol.py]
2026-03-06 feat: AI-controlled robot arm API server
    ## robot_server.py
    - Add POST /robot/play_sequence endpoint with smart joint settling
    - Polls at 6Hz, requires 3 consecutive stable readings within 0.5°
    - Falls back to settle_timeout (default 12s) if arm stalls
    - Per-step speed override support
    - Add repeat block support in sequence steps (recursive, any nesting depth)
    - {"repeat": N, "steps": [...]} expands inline during execution
    - Backward compatible with all existing flat sequences
    - Fix get_info/get_status: catch AttributeError for robot.enabled
    - Bump fibre.find_any timeout to 90s (USB enumeration is slow)
    ## fibre patches (macOS compatibility)
    - usbbulk_transport.py: Skip dev.reset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
    [protocol.py, robot_server.py, usbbulk_transport.py]
2026-03-11 feat: Astra Pro depth camera integration + design docs
    ## Camera Integration (EXP-013)
    ### New files
    - 3.Software/robot-server/depth_capture.cpp — C++ depth capture binary
    * Captures one 640x480 or 1280x1024 depth frame via OrbbecSDK v1
    * Outputs colorized PNG (red=close, blue=far, auto p5-p95 range)
    * Prints JSON stats to stdout (valid_pixels, depth_min/max/mean in mm)
    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
2026-03-11 feat: Phase 2 ctypes persistent depth driver + WebSocket stream
    ## depth_driver.py (new)
    - Loads libOrbbecSDK.dylib directly via ctypes — no subprocess
    - Device stays open between API calls (no per-call startup cost)
    - Binds C API: ob_create_context, ob_query_device_list, ob_create_pipeline,
    ob_config_enable_video_stream, ob_pipeline_wait_for_frameset, ob_frame_data, etc.
    - Warmup: discards first 10 frames for auto-exposure stabilization
    - Thread-safe: mutex serializes concurrent captures
    - Context manager support: with DepthDriver() as d: d.capture()
    - Key constant fixes: OB_STREAM_DEPTH=3 (not 1), OB_LOG_OFF=5
    ## camera_manager.py (rewrite)
    - PersistentDepthCamera: wraps DepthDriver,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
    [robot_server.py]
2026-03-11 docs: EXP-014 experiment log + .gitignore for robot-server
    - experiment_logs/EXP-014: Phase 2 ctypes persistent depth driver
    - Documents C API bindings, critical constant fixes (OB_STREAM_DEPTH=3, OB_LOG_OFF=5)
    - Performance results: ~1000x speedup on /camera/depth/stats
    - Architecture, implementation details, key learnings
    - experiment_logs/README.md: added EXP-014 to index
    - 3.Software/robot-server/.gitignore: exclude depth_capture binary, __pycache__, Log/
2026-03-11 docs: EXP-015 arm + camera combined sweep recording test
    - First combined test of robot arm movement + Astra Pro camera recording
    - Arm swept J1 -40°↔+40° × 5 cycles from raised position [J2=20°, J3=80°]
    - Used play_sequence repeat block for clean 5-cycle definition
    - 55s total, all 13 steps settled successfully (~5s per full swing)
    - Recorded 45s 1280×720 MP4 via ffmpeg, delivered to Feishu
    - Key finding: msg_type=media (not file) for video delivery
    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
2026-03-11 exp: EXP-016 depth vs FK tip validation — 3 iterations, camera geometry finding
    3 detection approaches tried:
    - v1: min-depth pixel → found sensor artifacts (73mm), not tip
    - v2: variance map → variance too low (arm barely moves in depth), useless
    - v3: pairwise frame diff → ~2000 tip pixels found, weak correlation (r=0.41)
    Root cause: camera faces arm head-on, J1 sweep is tangential to camera Z axis
    252mm FK lateral movement → only 27.5mm camera-X change (9x compression)
    Background subtraction reliable (8000+ arm px detected every pose)
    Camera position estimated: ~(464, 78, 171)mm in robot frame
    Options for EXP-017:
    A) Colored marker on tip → RGB detection + depth lookup
    B) Re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
2026-03-11 docs: EXP-017 failed visual approach attempt + camera endpoints
    - Add GET /camera/depth/raw endpoint (uint16 binary blob)
    - Add GET /camera/objects/detect endpoint (desk plane + blob detection)
    - EXP-017: visual approach to yellow object — failed
    - Root causes: wrong elbow config (J3=60-70 vs needed 120-130),
    depth subtraction fails when arm/objects at same depth,
    no reliable camera-robot transform
    - J1=-43 to -45 identified as yellow gear lateral range
    - Proposed better alternatives: structured calibration, top-down camera,
    wrist camera, or manual teach
    [robot_server.py]
2026-03-12 fix: proper USB disconnect detection + general vision system plan
    - get_robot(): add hasattr(dummy, 'robot') guard for post-startup USB loss
    Previously returned 500 AttributeError; now returns clean 503 with message
    - /robot/status: actually probe hardware (joint_1.angle) instead of blindly
    reporting 'connected'; returns {status: disconnected, detail: ...} when dead
    - docs/general-vision-plan.md: full plan for VLM-based general pick-and-place
    including self-calibration design, scene understanding module, hardware notes
    [robot_server.py]
2026-03-12 feat: auto-labeling dataset generator (self-supervised arm pose data)
    Sweeps arm through 255 poses (J1/J2/J3/J5 grid), captures RGB frame at each
    pose, runs background subtraction to get clean arm mask, auto-generates:
    - YOLO bbox label from arm mask bounding box
    - Tip pixel (topmost arm pixel)
    - Binary mask PNG
    - Metadata JSON (joint angles, FK data, pixel stats)
    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
2026-03-12 feat: hand dataset generator with tip-based hand isolation
    Uses 'distal 28% of arm pixels by distance from base' to extract
    the hand/wrist region from any arm mask — no XOR needed.
    - Avoids XOR noise (camera vibration, cable movement, desk objects)
    - hand_pixels: ~12k (was ~50k with XOR) — much more targeted
    - Auto-builds background if not found
    - 10 base poses × 20 wrist variations = 200 samples in ~13 min
2026-03-12 docs: EXP-018 exploration experiment — general vision system
    Full session log covering:
    - VLM arm tip detection (failed — ambiguous without tip marker)
    - GroundingDINO object detection (success — white cube, yellow squares)
    - Color segmentation for arm tip (partial)
    - Background subtraction arm segmentation (success)
    - Whole-arm self-labeling dataset: 255 samples, 0 failures
    - Hand region labeling: XOR failed, tip-fraction partially better but bbox still too large
    - Performance benchmarks, installed packages, open problems
2026-03-12 docs: EXP-019 yellow cover swap — hardware upgrade & vision characterization
    - Cover swap procedure + the 'PA!' incident (plastic clip, not broken board)
    - All 6 joints confirmed healthy post-swap
    - Depth camera: 74% valid pixels (improved IR reflectance)
    - Color segmentation: arm is permanently red (CNC) + yellow (printed)
    - Combined red+yellow mask strategy documented
    - Background subtraction remains primary arm detection method
2026-03-12 docs: EXP-000 origin log — before the experiments
    Narrative log of the assembly phase, written from assembly photos.
    Parts on a table, cables hand-crimped, the arm taking shape on a
    lab desk in what looks like an office (desk label: 300.K2).
    Written to remember where this all started.
